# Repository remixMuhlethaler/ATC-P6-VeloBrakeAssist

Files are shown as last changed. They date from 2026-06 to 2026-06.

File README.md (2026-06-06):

# VeloBrake Assist — ATC-P6

**An open-source assistive cycling device for users with limb differences.**

> Developed at EPFL as part of the Assistive Technology Challenge (ATC) 2025–2026.  
> Team: Camilla Varotto · Hema Gouled · N'zian Koffi · Remy Mühlethaler  

---

## Overview

VeloBrake Assist is a custom-fit braking aid designed for a user with ectrodactyly of the left hand. The device enables safe, independent braking on a standard bicycle. It adapts the open-source [Project Caroline by Macu4]([https://www.macu4.com](https://www.hackahealth.ch/project-caroline-2021)) to the user's specific hand morphology and target bike.

The device consists of three integrated subsystems:

- **Hand-grip** — a custom TPU + PETG mold shaped from the user's hand, providing a secure and comfortable interface between the hand and the handlebar.
- **Braking system** — a stainless steel cable mechanism that transmits the user's wrist/arm downward movement into modulated brake actuation.
- **Attachment mechanism** — a commercial steel pipe clamp designed to fit standardized handlebar (without coatings).

The prototype is functional and has been validated by the user on their own bicycle. Further improvements are planned (see [Future Work](#future-work)).

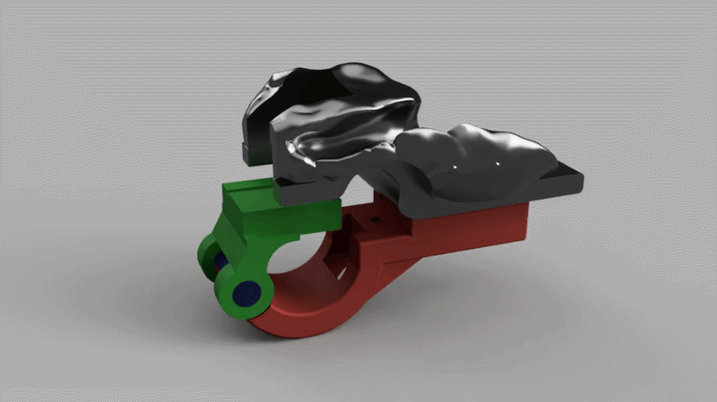
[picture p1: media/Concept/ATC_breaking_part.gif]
VeloBrake Assist Concept
 
## Media and Demonstrations

The operation of the prototype as well as the testing phases are documented in video format.

* [Access the complete Google Drive folder (Videos & Photos)](https://drive.google.com/drive/folders/1Wf3XGNz-UpR_hRMOGoVsbd66ucjs_gCT?usp=sharing)
---

## Repository structure

```
ATC-P6-VeloBrakeAssist/
├── docs/
│   ├── user_manual.pdf          # Assembly & use guide (≤3 pages)
│   ├── open_access_report.pdf   # Reproducibility report (≤10 pages)
│   └── final_presentation.pdf  # End-of-semester presentation (EPFL, 29.05.2026)
│
├── worksheets/
│   ├── traceability_matrix_v0.1.xlsx
│   ├── traceability_matrix_v0.2.xlsx
│   ├── traceability_matrix_v0.3.xlsx
│   └── traceability_matrix_v0.4.xlsx
│
├── cad/
│   ├── fusion/                  # Native Fusion 360 source files (.f3d)
│   ├── laser_cut/               # File for Laser cut the MDF piece on the top (.dxf)
│   └── exports/                 # Print-ready files (.stl)
├── media/
│   ├── photos/                  # Prototype photos (design iterations + final)
│   └── videos/                  # Verification & validation footage
│
└── README.md
```

---

## How to reproduce the prototype

Full step-by-step instructions are in [`docs/open_access_report.pdf`](docs/open_access_report.pdf).

Quick summary:

1. **Print the parts** — open the `.stl` files in `cad/exports/`. Recommended settings: PETG at 0.2 mm layer height. 
2. **Route the cable** — thread the stainless steel cable through the channel and crimp the end stops.
3. **Attach to the handlebar** — slide the bracket over the handlebar and tighten the fastening screw.

> **Note:** The hand-grip is user-specific. The current shape was molded from our user's hand using Fimo clay as an intermediate. To reproduce for a different user, reshape the mold in Fusion 360 using the `.f3d` source files in `cad/fusion/`.

---

## Design process

The project followed the **V-model** engineering process:

- **User requirements** (safety, comfort, portability & compatibility) were gathered through home visits and structured interviews.
- **System requirements** were derived: braking system, hand-grip, attachment mechanism.
- **Design & Prototype**, each subsystem went through design, prototyping, verification (bench tests), and validation (on-bike tests with the user).
- Three iterations of the traceability matrix and risk assessment tracked requirement coverage throughout the semester.

---

## Future work

The current prototype is functional but several improvements are identified for the next iteration:

- Formal mechanical testing (load, fatigue, release force)
- Integrated cable clamp for easier installation
- Metal shaft to improve attachment rigidity
- Compatibility testing on additional bike models

---

## Acknowledgements

Special thanks to our TAs Dounia and Aiden for their guidance throughout this project.  
This project builds on [Project Caroline by Macu4]([https://www.macu4.com](https://www.hackahealth.ch/project-caroline-2021)) — an open-source assistive cycling device.

---

*EPFL · Assistive Technology Challenge 2025–2026 · Group P6*

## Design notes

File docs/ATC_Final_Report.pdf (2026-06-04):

# VeloBrake Assist

# An Assistive Braking Device for Biking

Varotto Camilla, Hema Gouled, N’zian Koffi, Remy Mühlethaler

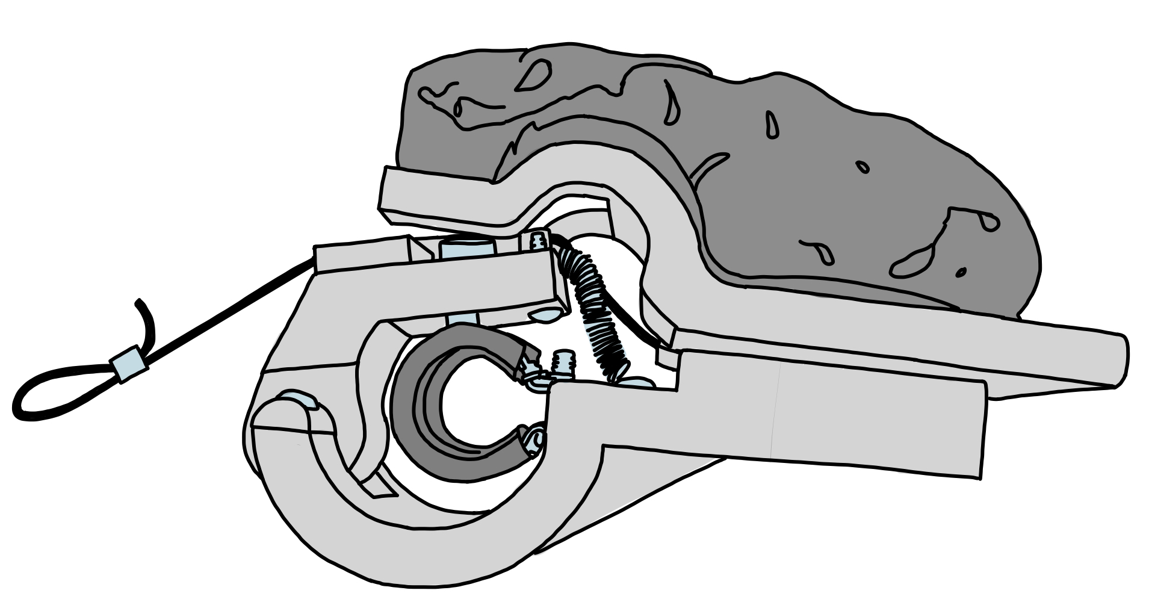
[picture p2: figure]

Open Access Report
Assistive Technology Challenge 2026 Group: P6, Adapted environment for ectrodactily Professors: Auke Ijspeert, Silvestro Micera, Josie Hughes TAs: Dounia Hassar, Aiden Xu

Lausanne, Spring 2026

## Contents

P6-ATC: Velobrake Assist

## 1. Introduction

VeloBrake Assist is an assistive device developed during a semester-long interdisciplinary project called Assistive Technology Challenge, organized by HackaHealth at EPFL (École Polytechnique Fédérale de Lausanne). Each team, composed of 4 Master’s students, was assigned a "challenger" with a specific need to solve an everyday challenge, adopting a "user-in-the-loop" approach.
The challenger assigned to this team is affected by ectrodactyly, also called split hand/foot malformation (SHFM), a rare congenital condition in which the development of the hand or foot is disturbed, causing the deficiency or absence of one or more central digits. The hands and feet of people with ectrodactyly are often described as "claw-like" due to their V-shaped appearance [3]. The challenger presented with one split hand, the left one, with the right one completely functional.
During the first meeting, the challenger described a daily life filled with constraints and limitations, and the continuous feeling of living in a world not shaped for them as they have issues with holding and grasping objects. One of the main things they wished to enjoy is biking. However, the conformation of their left hand does not allow them to grip the handlebar securely or to brake. Their goal was for the team to develop a device that could allow them to bike safely.
In this report, the development of VeloBrake Assist will be discussed, detailing the design choices and the iterative prototyping process behind them. Further steps needed to fully satisfy the needs of the challenger will also be presented.

## 2. Design Choices

### 2.1. User Requirements

### 2.1.1 Safety

As mentioned in the Introduction (Section 1), the user’s primary requirement is safety ("must-have"). To maneuver the bike safely, the user needs to grip the handlebars securely and to brake with both hands, not only the functional one. The braking mechanism should be modulable, allowing the user to slow down gradually rather than only stop abruptly, and should not activate accidentally. Additionally, immediate release of the handlebar must be possible in case of emergency, such as a fall. This was a critical limitation of a previous assistive tool they used (Figure 6.H) and the main reason they never felt fully safe while biking. Lastly, it should be sturdy enough to withstand the forces experienced while biking and braking.

2

### 2.1.2 Comfort

Comfort is also a key requirement ("must-have"); the device should therefore be mounted on the bike rather than worn. It should not feel bulky, but shaped to fit the user’s hand, and it should allow for natural and coordinated control of the bike.

### 2.1.3 Portability

Additionally, portability was identified as a desirable feature ("nice-to-have"). The device should be easily mountable, removable, and compatible with different bikes. The ideal scenario described by the user would be to carry the device in a backpack and mount it on any city bike when needed.

### 2.1.4 Support for Chronic Back Pain Management

Lastly, the user also reported suffering from chronic back pain, resulting from the overuse of the right hand to perform most daily actions. This leads to muscular imbalance between the two sides of the body, causing uneven load on the spine and additional issues while biking. While this condition is not directly addressed by the device, the user expressed the need for a solution that could help reduce this imbalance over time.

### 2.2. System Requirements

The user’s needs were translated into system requirements that guided the design of the device.

### 2.2.1 Braking System

The core of the device will be a braking system based on direct mechanical actuation of the brake through a cable. Braking shall be activated by a downward push of the wrist, a natural and comfortable movement for the user, and it shall be proportional to the force applied. The mechanism should be entirely passive, with no electronic components, ensuring simplicity and reliability. A spring return mechanism will be integrated to prevent accidental activation.

### 2.2.2 Hand-grip

To ensure both comfort and a secure grip, the device should incorporate a hand grip shaped to fit the user’s hand specifically, made from a soft material to maximize comfort during use.

3

### 2.2.3 Cable & Attachment Mechanism

Portability and compatibility will be addressed through two main design choices. First, a cable-based actuation system to ensure compatibility with various brake designs. Second, a secure attachment mechanism to fit the standardized handlebar diameter (removing the handlebar’s coatings), allowing the device to be mounted and removed from different bikes.

### 2.2.4 Weighted Sleeve

Finally, a weighted forearm sleeve should be used to address the muscular imbalance caused by chronic overuse of the right hand. A sleeve design should be chosen over conventional weighted tools, as the latter concentrate load on a single point of the arm, whereas the sleeve distributes it evenly across the forearm, which ensure comfortability for the user.

### 2.3. Final Design Specifications

Write about materials (PET-CF for robustness), specific design choices (eg the hole to fasten the attachment mechanism’s screw, type of screws), key design parameters.. The final design was build specifically for the challenger’s bike which was used for validation and verification, prioritizing robustness and safety on the user’s bike first and then compromising with some design specifications in order to create something that could be adaptable to different bikes.

### 2.3.1 Braking Mechanism: 3D designed parts, cable, spring

### 2.3.2 Hand-grip

I think we also need to ask sebastian which final parameters where used for the printing of TPU.

### 2.3.3 Clamping Collar & Fastening Screw

### 2.3.4 LaceUp Arm Sleeves

After discussing with the user, the "LaceUp Arm Sleeves" (Figure 6.J), a pair of weighted compression sleeves made with LYCRA® fiber weighing 1 lb each, were purchased from LaceUp (size Small/Medium) [1], an American brand specializing in weighted sport garments.

4

## 3. Reproducing Prototype

This is where the iterative, hands-on reality lives. Because design and prototyping were coupled for you, structure this as rounds of iteration rather than a linear list of steps:

3.1. 3D Printing Iterations

3D printing iterations (what changed between versions and why)

### 3.2. Molded Hand-grip

Obtaining an accurate mold of the user’s hand was the most user-specific step of the entire process. During one of the early sessions with the user, Pâte Fimo (a polymer clay) was used to capture the natural grip position of the left hand directly on the handlebar of the user’s own bike using a platform in PETG similar to the one used in the final design. This approach was key: it ensured that the resulting shape reflected not an idealized grasp, but the actual posture adopted during riding. The hardened Fimo mold was then 3D scanned to obtain a digital model, which was cleaned and prepared for printing. The first print was made in PETG to verify the fit and general shape. While dimensionally accurate, the rigidity of the material made the grip uncomfortable against the user’s skin. A second version was printed in TPU (thermoplastic polyurethane) to introduce softness. After user testing, the printing parameters were adjusted reducing infill and perimeter to obtain a softer and more compliant result that the user found comfortable and secure.

### 3.3. Attachment Mechanism

Attachment mechanism trials (what failed, what worked)

### 3.4. Bike Repair

The user’s bicycle required significant maintenance. The bicycle was collected from the user’s home and transported to PointVelo, the on-campus bicycle repair service, where the necessary repairs were carried out with the help of the staff.
The kickstand was first re-secured, as it had become loose due to some missing fastening screws. The tires were then inspected, as the user had reported rapid pressure loss. No punctures were found and the issue was attributed to the prolonged inactivity of the bike. The tires were then reinflated.

5

The brake cables were adjusted to reduce lever travel distance. This was achieved by partially unscrewing the cable anchor bolt on each brake caliper, pulling the cable through to take up the slack, and re-securing it. This adjustment was necessary to shorten the actuation range of the levers and free up sufficient clearance on the handlebar for the device to be mounted.
Finally, recurrent chain derailment during gear shifting was addressed by installing a rubber-tipped set screw on the seat tube, acting as a mechanical stop to prevent the chain from dropping off during gear changes.

### 3.5. User testing sessions for Validation and Verification

their feedback, and what it changed

## 4. Further Improvements

The current prototype successfully demonstrates the core concept of VeloBrake Assist, but several limitations were identified during the project that would need to be addressed before the device could be considered production-ready.

### 4.1. Metal Shaft

The most pressing mechanical concern is the long-term durability of the 3D-printed parts. Although PET-CF was chosen for its stiffness, the pivot axis of the lever is a point of concentrated stress and would benefit from being replaced by a metal shaft machined to tolerance. This upgrade would significantly increase the lifespan of the device and its resistance to repeated braking cycles.

### 4.2. Cable Clamp

The cable attachment is another area for improvement. Currently, the cable is terminated with a crimped end which, while functional, requires a specific tool to adjust or replace. A cable clamp system was designed as a next step to allow tool-free cable length adjustment, making the device more accessible for the user to install and transfer between different bikes. However, the 2mm-cable clamp that was purchased [2] proved too bulky, obstructing the sliding of the cable and limiting the braking action, and was therefore not implemented in the final prototype.

6

### 4.3. Stability Across Different Bikes

The current attachment mechanism was designed around the user’s own bike, with the handlebar grip removed to ensure a secure fit. While this approach achieves good stability on the current setup, transferring the device to a different bike may introduce variability due to differences in handlebar and brake geometry.
A promising avenue to address this would be a dual-point attachment system. A primary, rigid fixation point just inboard of the grip (where handlebar diameters are largely standardised across city bikes) would bear the majority of the braking forces. A secondary, lighter contact point at the grip itself would provide rotational stability without requiring a tight clamp, accommodating slight variations in grip diameter found across different bikes. This configuration could preserve the stability achieved on the current prototype while making the device genuinely transferable. However, the feasibility of this approach depends critically on the clamping force achievable at the primary fixation point: sufficient torque and a secure fastening system would be essential to ensure the device does not rotate or slip under braking load.

### 4.4. Mechanical and Environmental Testing

The prototype was validated through user testing sessions but has not undergone formal mechanical testing. Quantifying the forces involved during braking at the pivot axis, the cable attachment point, and the handlebar clamp would allow the design to be optimised and failure modes to be identified. This is particularly relevant if the device were to be reproduced or adapted for other users, as the current prototype should be regarded as a proof of concept.
Additionally, the device has not been tested under real-world weather conditions. Rain, temperature variation, and UV exposure are all likely to affect the mechanical properties of the printed parts and the cable over time. Weatherproofing the design through appropriate material selection and protective coatings would be necessary for reliable everyday outdoor use.

### 4.5. Two-hands device

Early in the design process, the possibility of developing a two-handed version of the device was considered, motivated by the user’s requirement for natural and coordinated bilateral movement. Such a configuration would place an assistive device on both handlebars, allowing the user to brake with a coordinated movement.
However, this concept was not pursued for two main reasons. First, the right handlebar controls gear shifting; attaching a fixed grip platform on this side would make it difficult

7

for the user from operating the gear lever. Second, having both hands resting on the device rather than one directly on the handlebar poses a significant safety risk in case of mechanical failure. Given that the prototype has not undergone formal mechanical testing, it was considered essential that the user retains at least one hand in direct contact with the handlebar at all times, as a safety measure. The priority was therefore to validate the braking function on the left side first, leaving the two-handed configuration as a potential avenue for future exploration once the device has been thoroughly tested.

## 5. Conclusions

8

## 6. Figures

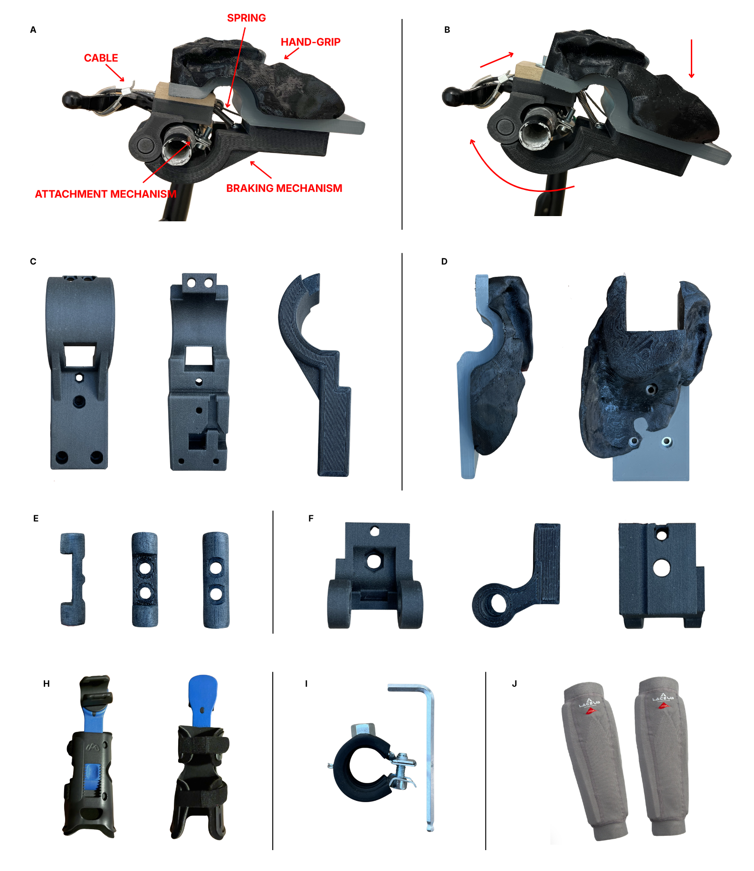
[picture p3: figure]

Figure 1: A. B. C. D. E. F. G. H. Frontal and dorsal view of the tool that the user previously used for biking; I. J. "LaceUp Arm Sleeves" purchased for the management of the challenger’s chronic back pain.

9

## References

[1] LaceUp. LaceUp Arm Sleeves. https://www.laceup.com/products/laceup-sleeves. Accessed: June 2026. 2026.
[2] SteelRopes24. Cable Gripper Clamp. https : / / www . steelropes24 . com / cable -gripper-clamp. (https://www.steelropes24.com/cable-gripper-clamp) Accessed: June 2026. 2026.
[3] Wikipedia. Ectrodactyly. https : / / en . wikipedia . org / wiki / Ectrodactyly. (https://en.wikipedia.org/wiki/Ectrodactyly) Accessed: June 2026. 2025.

10

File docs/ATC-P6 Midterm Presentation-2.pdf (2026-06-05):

# ATCP6

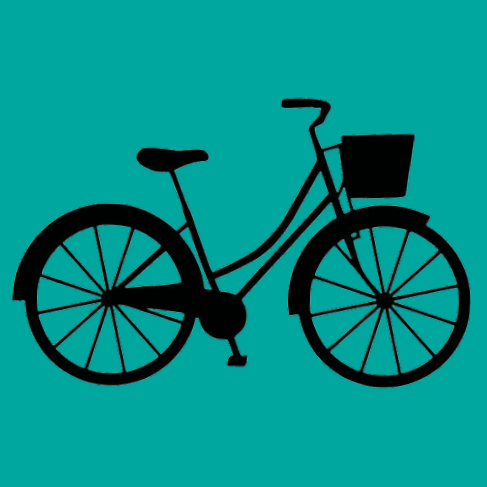
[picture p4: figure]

# Assistive Braking Device for Biking

Camilla Varotto, Hema Gouled, Nʼzian Koffi, Remy Mühlethaler

1

ATCP6 | 02.04.2026

2

# Presentation plan

- Definition of User Requirements
- Definition of System Specifications
- Existing solutions
- Brainstorming: presentation of possible ideas
- Presentation of our concept
- Budget Plan
- Future planning
- Expected Challenges

ATCP6

3

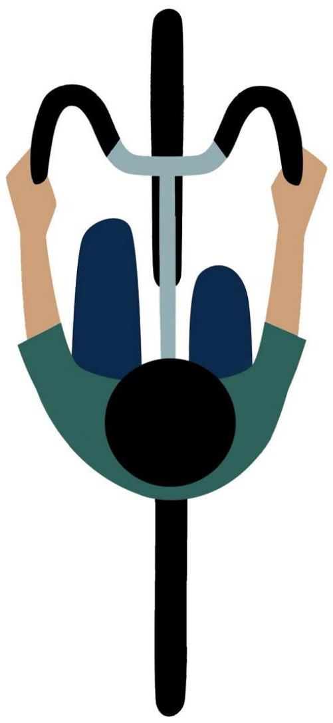
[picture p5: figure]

# What is the challenge?

- User with ectrodactyly: rare
genetic condition causing missing or malformed fingers
- A world not shaped for them: issues with grasping and holding objects
- Their wish: biking safely

4

# What are the needs of our challenger?

Safety
❏ | Secure grip for stable maneuvering
❏ | Ability to brake with the left hand
❏ | Modulable braking control
❏ | Immediate hand release in emergencies
❏ | Mechanism that avoids accidental braking activation
Comfort
❏ | Not worn by the challenger, but mounted on the bike
❏ | Natural, coordinated hand movement
❏ | Ergonomic device, shaped for the user
Portability & Compatibility
❏ | Easily mountable without assistance
❏ | Compatible with different bike types
❏ | Portable and easy to carry

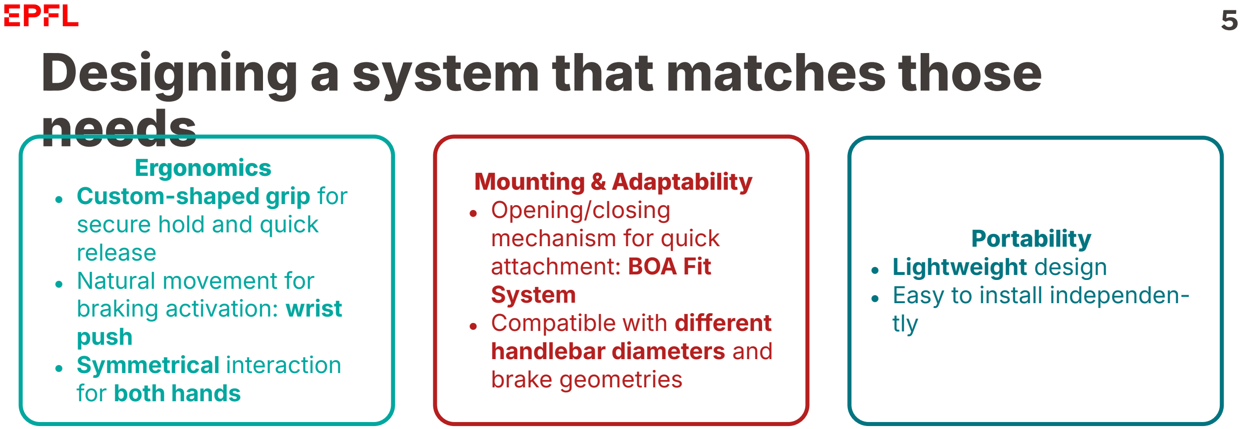
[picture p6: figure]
Designing a system that matches those needs; Ergonomics ● Custom-shaped grip for secure hold and quick release ● Natural movement for braking activation: wrist push ● Symmetrical interaction for both hands; Mounting & Adaptability ● Opening/closing mechanism for quick attachment: BOA Fit System ● Compatible with different handlebar diameters and brake geometries; Portability ● Lightweight design ● Easy to install independen- tly
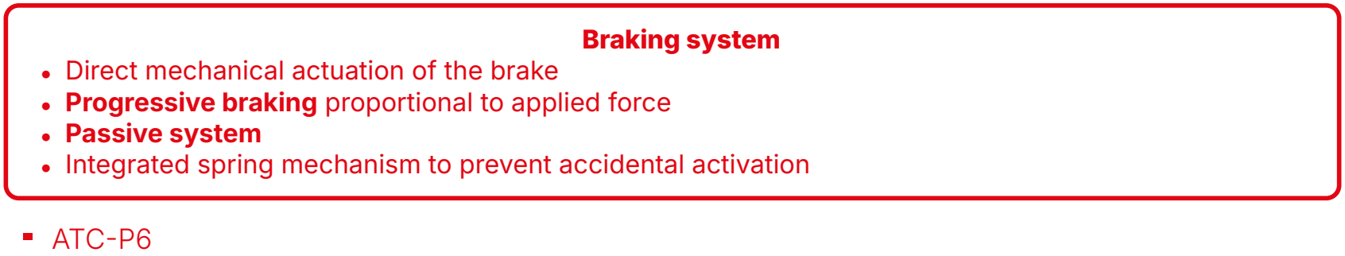
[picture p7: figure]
Braking system; ● Passive system

- Direct mechanical actuation of the brake
- Progressive braking proportional to applied force
- Integrated spring mechanism to prevent accidental activation

# Review of existing solutions

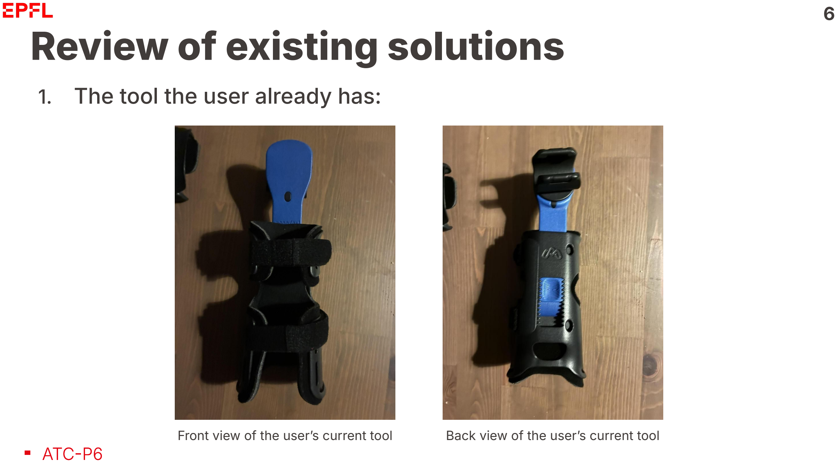
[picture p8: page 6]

6

1. The tool the user already has:
Front view of the userʼs current tool | Back view of the userʼs current tool

7

# Review of existing solutions

1. The tool the user already has:

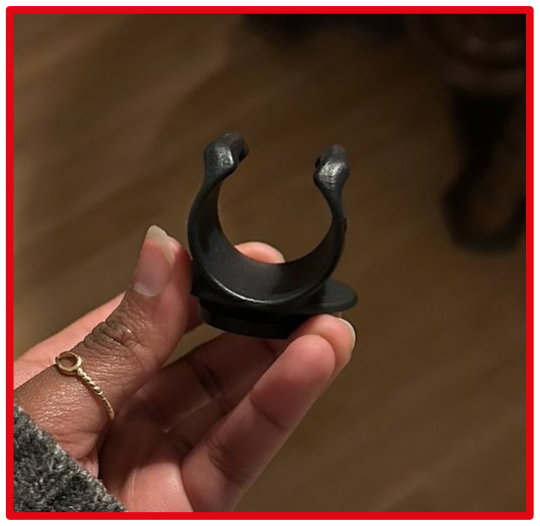
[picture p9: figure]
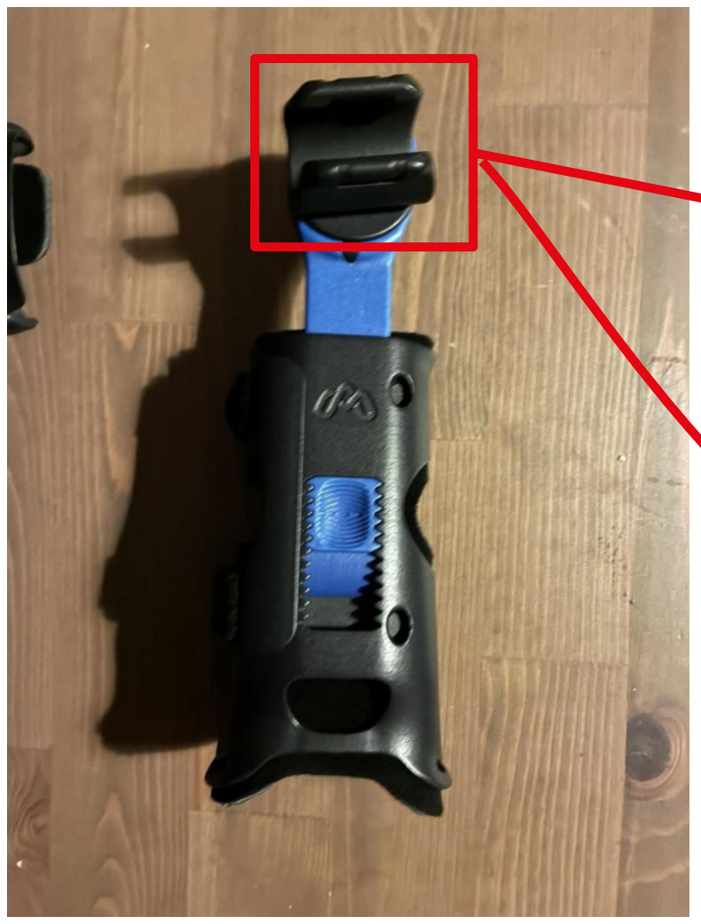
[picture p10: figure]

bike extension

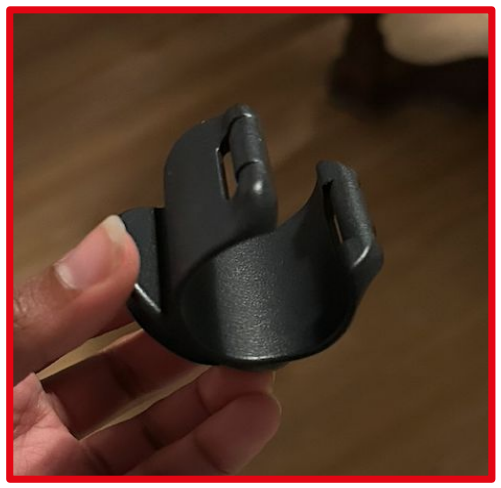
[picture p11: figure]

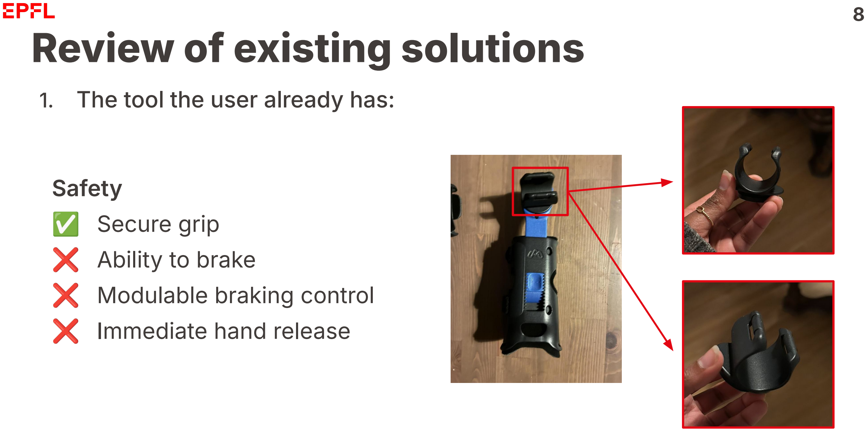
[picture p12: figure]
Safety Secure grip Ability to brake Modulable braking control Immediate hand release; 1. The tool the user already has:; Review of existing solutions

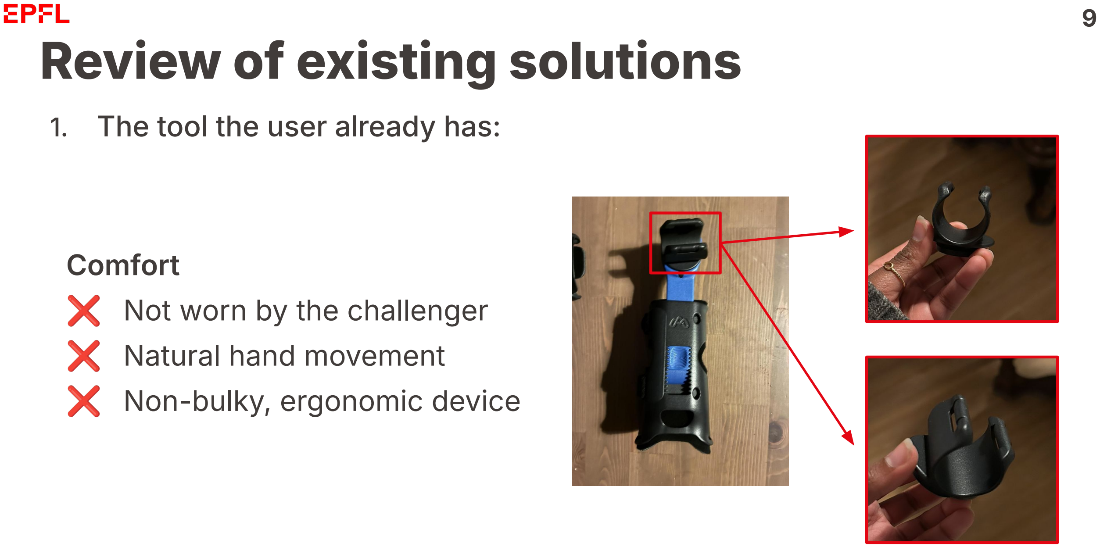
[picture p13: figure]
Comfort Not worn by the challenger Natural hand movement Non-bulky, ergonomic device; Review of existing solutions; 1. The tool the user already has:

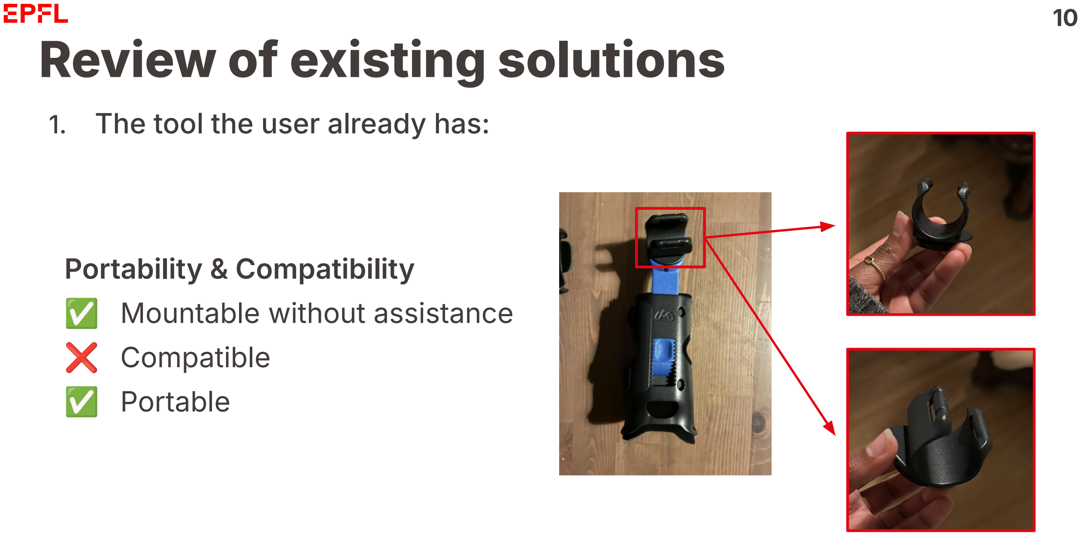
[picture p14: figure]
Portability & Compatibility Mountable without assistance Compatible Portable; Review of existing solutions; 1. The tool the user already has:

11

# Review of existing solutions

2. Coaster Brake (pedal braking):

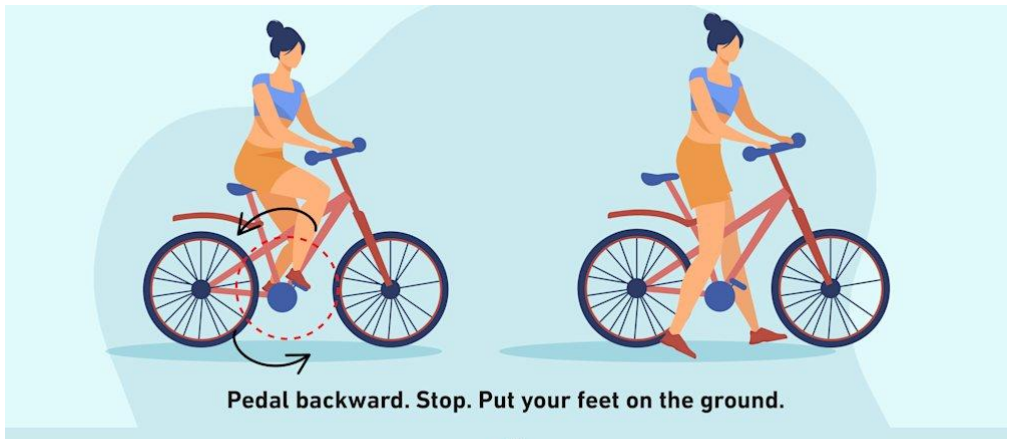
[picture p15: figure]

12

# Review of existing solutions

2. Coaster Brake (pedal braking):

Safety
Secure grip
Ability to brake
Modulable braking control
Immediate hand release

13

# Review of existing solutions

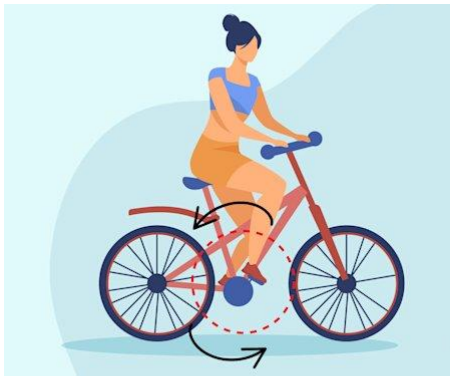
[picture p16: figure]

2. Coaster Brake (pedal braking):

Comfort
Not worn by the challenger Natural movement
Non-bulky, ergonomic device

14

# Review of existing solutions

2. Coaster Brake (pedal braking):

Portability & Compatibility Mountable without assistance Compatible
Portable

15

# Review of existing solutions

3. Project “Carolineˮ by Macu4

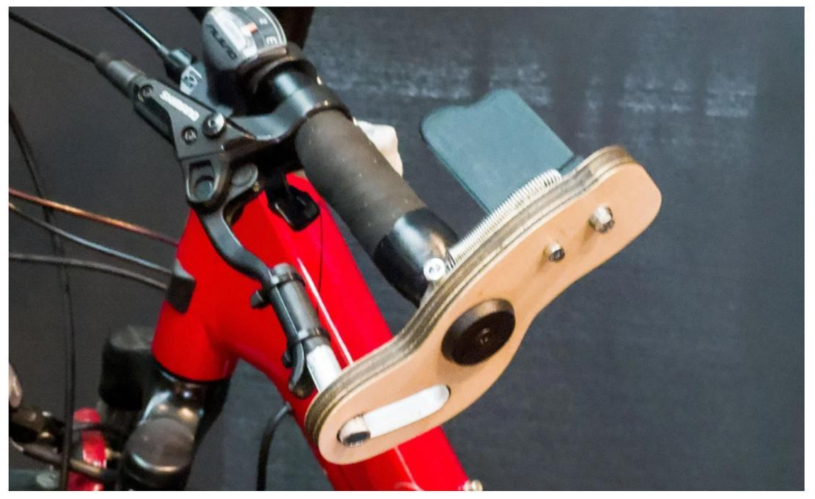
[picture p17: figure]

Project “Carolineˮ custom design installed on real bike

16

# Review of existing solutions

3. Project “Carolineˮ by Macu4

Safety
Secure grip
Ability to brake
Modulable braking control
Immediate hand release

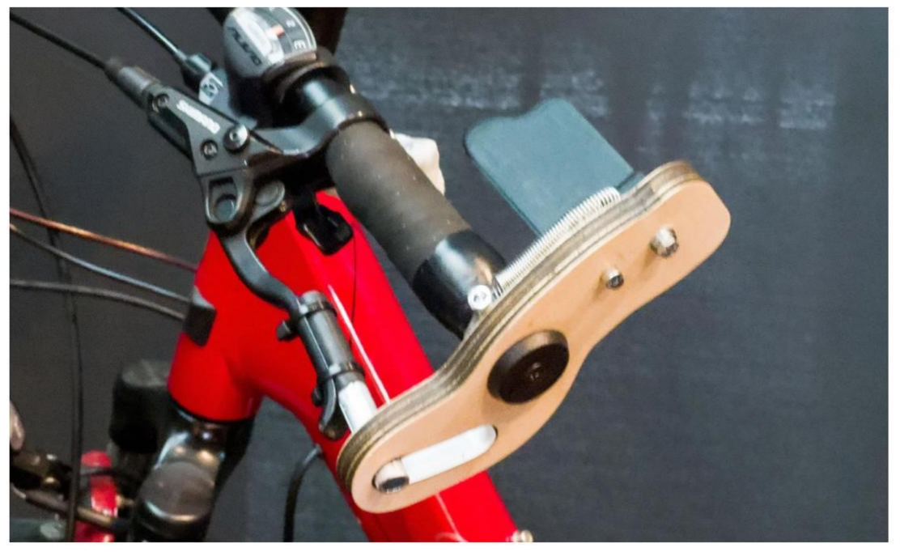
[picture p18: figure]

Project “Carolineˮ custom design installed on real bike

17

# Review of existing solutions

3. Project “Carolineˮ by Macu4

Comfort
Not worn by the challenger Natural hand movements

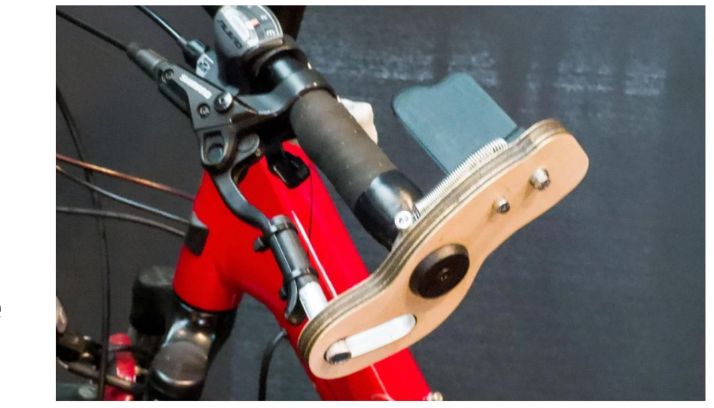
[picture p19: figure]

Non-bulky, ergonomic device

Project “Carolineˮ custom design installed on real bike

18

# Review of existing solutions

3. Project “Carolineˮ by Macu4

Portability & Compatibility Mountable without assistance Compatible
Portable

Project “Carolineˮ custom design installed on real bike

19

# Concept brainstorming:

1. Primal ideas

# Concept brainstorming:

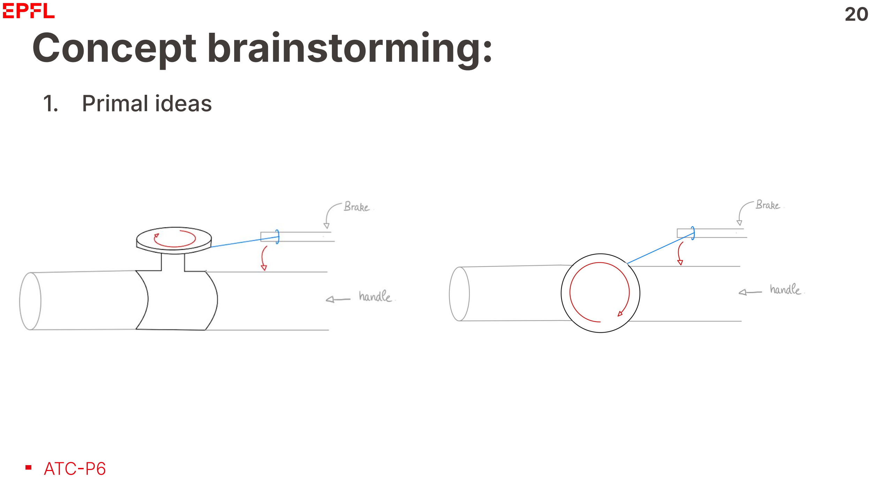
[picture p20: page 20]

20

1. Primal ideas

21

# Concept brainstorming:

2. After the feedback

⇒ Adapt the Macu4 mechanism

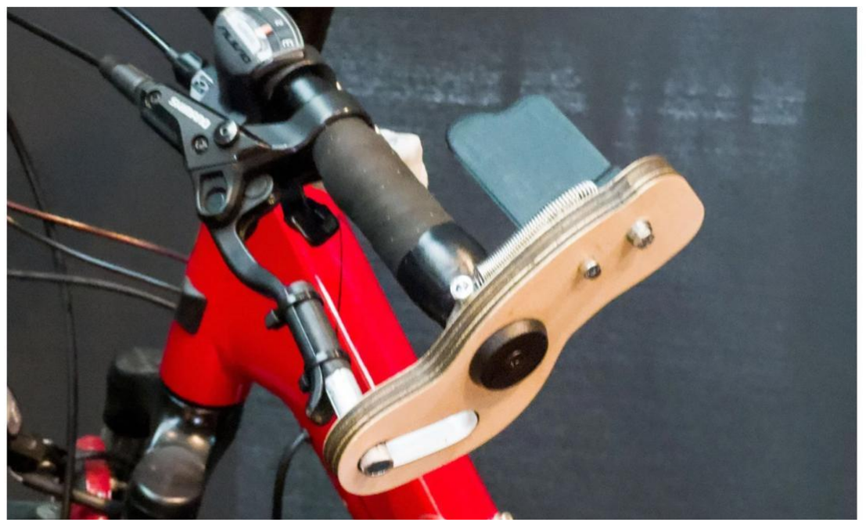
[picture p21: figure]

Idea approved by:
The challenger
The challengerʼs physical
therapist
The founder of Macu4

# Design of the prototype

22

Isometric view of the concept

# The concept

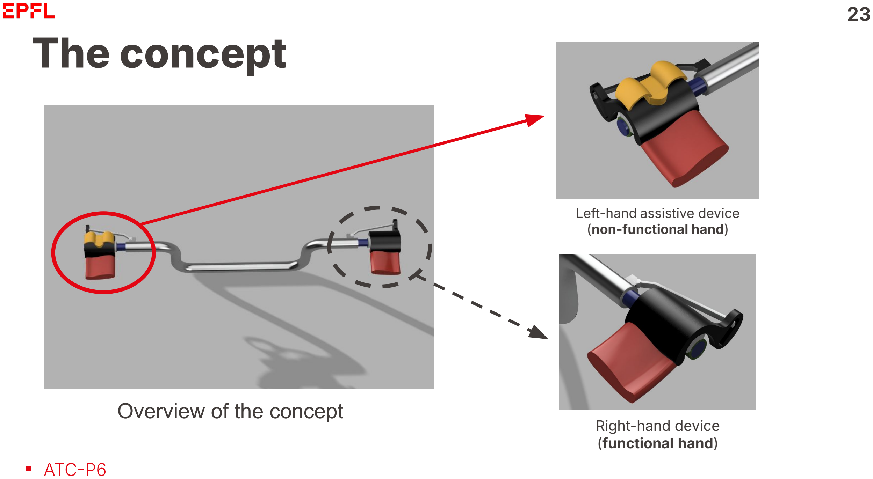
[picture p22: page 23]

23

Overview of the concept

Left-hand assistive device (non-functional hand)

Right-hand device
(functional hand)

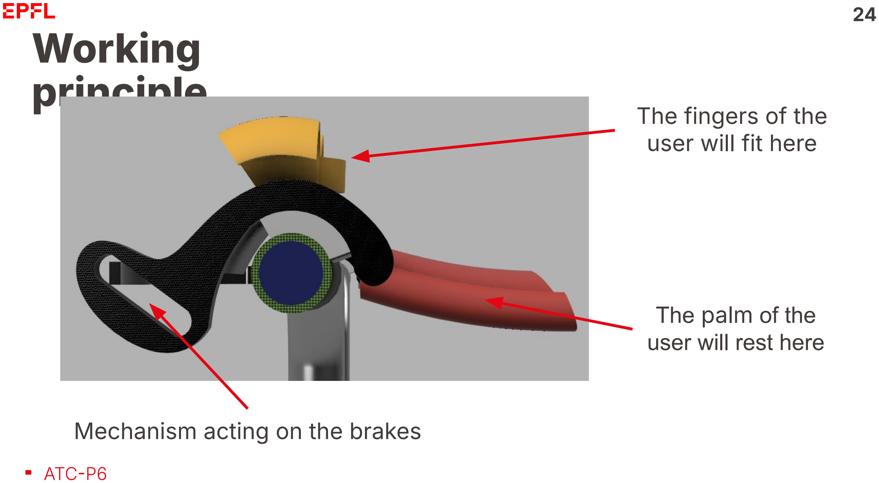
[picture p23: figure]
Working principle; The palm of the; user will rest here; The fingers of the user will fit here; Mechanism acting on the brakes

# Working principle

25

Resting position

Rotating

Braking

Brakes activation

# Adaptability on any bike

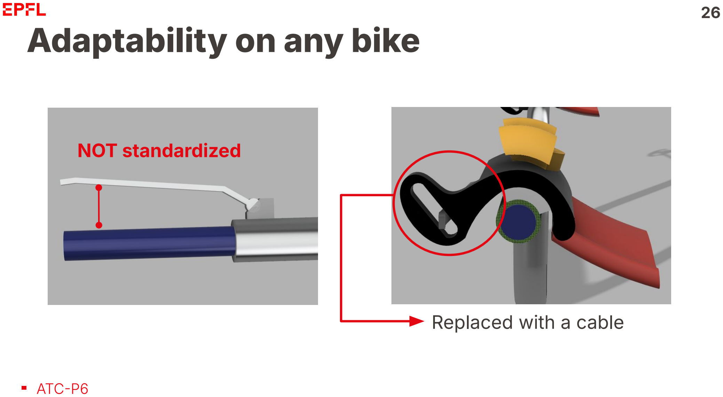
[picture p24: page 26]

26

NOT standardized

Replaced with a cable

# Adaptability on any bike

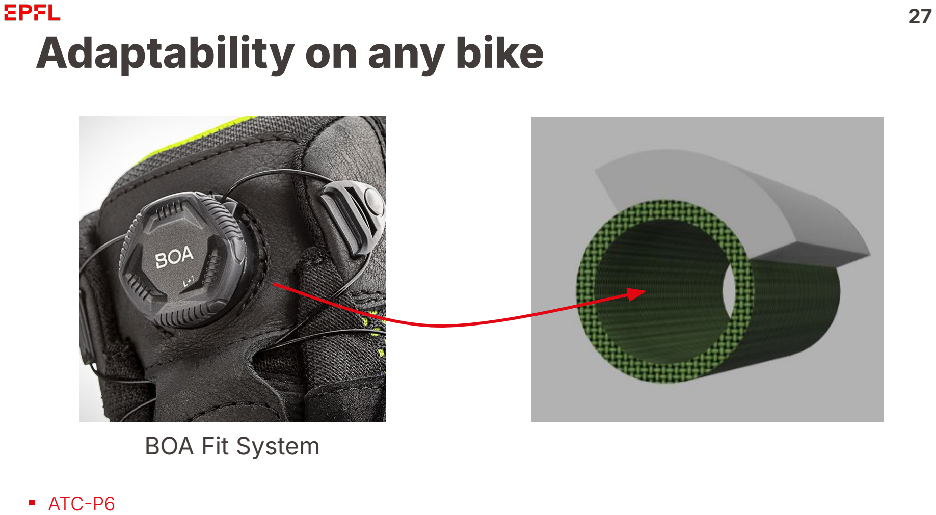
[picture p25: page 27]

27

BOA Fit System

# Pivot mechanism

28

Frame can rotate
relative to the grey
slider block
Dovetail sliding
mechanism (in the
grey block)

29

# Comfort 3D molding)


Adapted to the user,
3D molding

30

# Planning

ATC; team; Prototyping at DLL; Verification and validation; Final; presentation; Documentation; Iteration and switch material if needed

User | Testing on their bike and giving feedback 3D scan of their hand and

31

# Budget Plan

Category | Amount CHF | % Total | Notes
Travel & visits | 50.- | 5.8%
PLA 3D printing | 150.- | 17.6% | For testing & prototyping in 3D
Mechanical components | 50.- | 5.8% | Ball bearing, screws, springs, sliders…
BOA system | 60.- | 7% | Or similar
Stainless steel cable | 40.- | 4.7% | Sertissage & cable
Metal and composite machining | 500.- | 58.8% | PLA probably not strong enough
Total | 850.- | 100% | Initial allocated budget 1000.-

ID | Hazard | Risk | S | O | R | Mitigation Measure
R1 | Mechanical failure | Device does not brake/ slips | 3 | 2 | 6 | Material testing, safety factor in design, user testing protocol
R2 | Accidental activation | Brake triggered unintentionally while cycling | 4 | 2 | 8 | Lo-ratchet safety mechanism; resistance threshold tested with user
R3 | Poor fit/ comfort | Device is painful or unusable by challenger | 3 | 2 | 6 | Iterative prototype fitting sessions; adjustable straps & sizing
R4 | Bike incompatibility | Device cannot attach to all bike models | 2 | 3 | 6 | Universal mount design; tested on 2+ bike types before delivery

# Risk Assessment

33

# Any question?

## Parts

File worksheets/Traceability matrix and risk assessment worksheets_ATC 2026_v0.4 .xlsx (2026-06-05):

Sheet: Traceability matrix
User Requirement Specifications |  |  | Design Input Requirements |  | Verification |  |  |  | Validation
URS ID | URS | Importance [MUST / NICE TO HAVE] | DIR ID | DIR | Plan/method | Report result | Pass? [Y/N] | Comment | Plan / method | Report / result | Pass? [Y/N] | Comment
URS-01 | User wants to safely grip a bicycle handle to manouver it | MUST | DIR-01 | The device shall have a custom shape personalized for the user hand so that they can easily grip and hold on to the device which is mounted on the bike handle. | 3D design and modeling of the user hand with 3D scan | The user confirmed they could easily hold on to the custom-grip. | Y |  | Functional test with user: user confirmed ability to grip and manoeuvre the bike. | The user confirmed they could comfortably and securely grip the device while riding. | Y
URS-02 | User wants to be able to brake with her left hand when biking. | MUST | DIR-02 | The device will activate the brake mechanically whenever the user pushes down with her wrist on a platform. | Design of a device with the user input | Still needs to be tested with the user, but the mechanism pulls the brake when the lever is pushed down. | Y | Still needs validation. | Functional braking test with user. | The user confirmed the braking mechanism activates correctly when the wrist pushes down on the platform. | Y
URS-03 | User wants a device that can adapt to all bikes and that be easily switched on different bikes. | NICE TO HAVE | DIR-03 | The device shall have modulable parts with an opening mechanism so that it can be temporarily latched onto the bike handle and the brake. These parts will also need to be adaptable to different bike handles diameters and different brake-handle angles. | ~~~~BOA system, straps~~, modulable mechanism with a fastening screw~~ | The device can be mounted on different bikes with standard-sized handle bars by tightening and untightening a screw directly in the bike handle of the bike. To mount the device the handle coatings will need to be removed. The use of a cable to pull the brake allows the device to be mounted on bikes with different brake-handle angles. | Y |  | Mounting test on two different standard-sized bikes. | The device can be mounted on and removed from standard-sized handlebars, and the cable system adapts to different brake-handle angles. However, switching between bikes requires prior removal of the handlebar grip coating, which is a one-time manual step and not a quick swap. The "easily switched" aspect of the requirement is therefore not fully met. | N | The original requirement of easy switching between bikes has been partially abandoned for safety reason. The device is demountable and compatible with standard handlebars, but mounting requires the handlebar grip coating to be removed beforehand, which is feasible.
URS-04 | User wants to be able to remove their hand from the bike handle in case of urgency | MUST | DIR-04 | The custom shaped part of device that allows gripping shall also enable easy and quick removal of the user's hand. | 3D design and modeling of the user hand with 3D scan | The hand-grip doesn't trap the user's hand, confirmed with the user. | Y |  | Emergency release test with user. | The user confirmed they could remove their hand quickly and without difficulty in a simulated emergency scenario. | Y
URS-05 | User wants a device that does not feel bulky or unnatural. | NICE TO HAVE | DIR-05 | The device shall be mounted on the bike, not worn by the user. The movement performed to activate the braking system shall be natural, such as pushing down on a platform/lever with her wrist. | Design and discuss with the user's input. | Still needs to be confirmed with the user. However, the device was designed to be mounted on the bike and the natural activating movement was discussed and confimed with the user . | Y | Still needs validation. | User feedback session on comfort and naturalness of activation movement. | The user confirmed the activation movement felt natural and that the device did not feel bulky or intrusive. | Y
URS-06 | User wants a device that is mountable independtly by them without requiring the assistance from another person. | NICE TO HAVE | DIR-06 | The opening-closing mechanism used to make the device mountable on different bikes shall be easy to operate. The mounting/dismounting mechanism shall be kept as simple as possible. | Design and discuss with the user's input. | Still needs to be confirmed with the user. However, the device requires the handlebar coatings to be taken off, which is not something easy and quick to do. In principle, we achieved a design that is quite easy to mount with one hand with reduced functionality, but the user will need help to remove the coatings. | N |  | Independent mounting trial with user. | The user was able to mount the device on the handlebar independently with one hand; however, removal of the handlebar coatings required assistance. This requirement is partially met. | N | Mounting the device independently requires removal of the handlebar coatings, which the user cannot perform alone. Accepted as a known limitation given the chosen fixation approach.
URS-07 | Users wants a device that she can carry around and mount in case she needs to rent a city bike | NICE TO HAVE | DIR-07 | The device shall not be to bulky and heavy, but made of light materials. | Weight the device | The device is light, but for what we mentioned above, it won't be usable on city bikes as the user won't be able or allowed to remove the handlebar coatings off them. |  | It is light, but not mountable on city bikes. | City-bike compatibility test. | The device cannot be mounted on city bikes because the handlebar coatings cannot be removed by the user or may not be removed at all on rental bikes. | N | Accepted limitation: the fixation approach requires handlebar coating removal, which is not feasible on rental/city bikes. The device remains functional on personal bikes.
URS-08 | User wants to perform the same movement with both hands. So that coordination is facilitated. | MUST | DIR-08 | Two devices shall be made, one for the functional and one for the non functional hand. The same mechanism (pushing down with her wrist) will be applied ot both, but with slighlty different implementation to adapt them to the different shapes of her hands. | Design and discuss with the user's input. | Two similar devices with the same mechanism and different hand-grips were designed. | Y |  | The two-device approach was abandoned for safety reasons (risk of obstructing access to the gear shifters) and to preserve the user's access to the handlebar controls on the right side. | The user confirmed she felt comfortable and safe using only the left-hand device. The right side was kept free to allow unrestricted access to the gear shifters and other handlebar controls. | N | The bilateral symmetry goal was deprioritised in favour of safety and usability.
URS-09 | User wants a mechanism that is safe and it does not activate by mistake. | MUST | DIR-09 | The device shall have a spring counteracting the sliding mechanism used to activate the brake, so that the force to activate it will not be minimal. | Design | Still needs to be tested with the user, but the mechanism works. | Y | Still needs validation. | Safety activation threshold test with user. | The user confirmed the spring resistance prevents accidental activation; the mechanism requires a deliberate downward push to engage. | Y
URS-10 | Users wants a device that brakes modulably, not only brakes completely or not. | MUST | DIR-10 | The device will be mechanic and passive activated directly by the user movement. The degree of braking will be determined by how hard the user pushes down with their wrist. | Design | Still needs to be tested with the user, but the mechanism works. | Y | Still needs validation. | Modular braking test across a range of applied forces. | The user confirmed that varying wrist pressure produces proportional braking, with no binary on/off behaviour observed. | Y
URS-11 | User wants a weighted sleeve to strength train her left side and balance the weight. | NICE TO HAVE | DIR-11 |  | Design | Sleeve was ordered online. | Y | Still not delivered. | User trial with weighted sleeve. | The user confirmed the sleeve provides perceptible resistance on the left side and complements the device for strength training purposes. | Y

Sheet: Risk assessment
Risk identification, evaluation and control |  |  |  |  |  |  | Risk verification
Risk ID | Hazard | Risk | Severity ("S") | Occurrence ("O") | Risk ("R") | Risk control measure | Risk mitigated? [Y/N] | Comment
R1 | Mechanical failure | Device does not brake/slips | 3 | 2 | 6 | Material testing, safety factor in design, user testing protocol | Y | No slippage risk identified. However, no fatigue testing has been conducted on the mechanism. Force distribution across contact zones has been optimized and the device has been designed to maximize structural robustness, but residual risk of breakage under repeated loading cannot be fully excluded.
R2 | Accidental activation | Brake triggered unintentionally while cycling | 4 | 2 | 8 | Lo-ratchet safety mechanism; resistance threshold tested with user | Y | Spring has been added to the mechanism to actively prevent unintentional engagement. Resistance threshold validated through testing.
R3 | Poor fit/comfort | Device is painful or unusable by challenger | 3 | 2 | 6 | Iterative prototype fitting sessions; custom hand mold produced for the challenger to ensure anatomical fit. | Y | A custom hand mold was produced for the challenger to ensure an anatomical fit. The resulting device fit was reviewed and approved by the challenger.
R4 | Bike incompatibility | Device cannot attach to all bike models | 2 | 3 | 6 | A secure screw-based fixation was chosen over a universal mount to guarantee reliable attachment and eliminate the risk of slippage or improper mounting on standard bikes. Compatibility is limited to bikes whose handlebar coatings can be removed. | N | The device is not compatible with bikes fitted with grip covers on the handlebars. A good fixation mount was deliberately chosen over a universal solution to prioritize secure and reliable attachment, eliminating the risk of improper fixation.

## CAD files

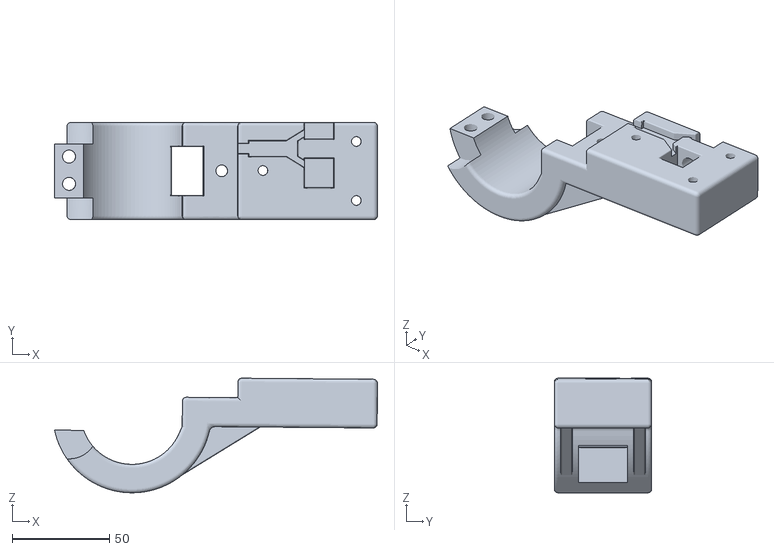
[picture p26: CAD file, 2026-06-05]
cad/exports/ATC_breaking_rotating_part.stl
165.7 x 50.0 x 58.8

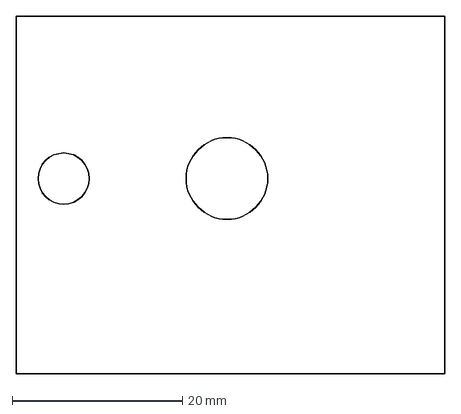
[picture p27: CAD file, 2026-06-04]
cad/laser_cut/Decoupe_LASER_MDF.dxf
50.3 x 42.0 mm

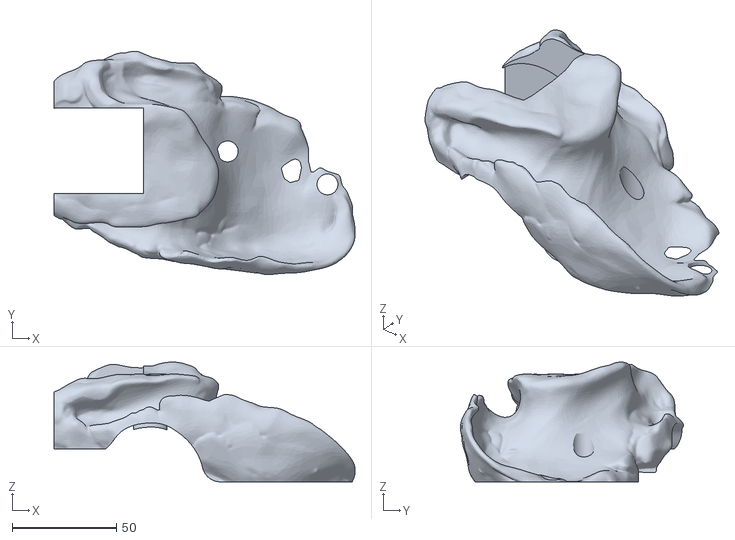
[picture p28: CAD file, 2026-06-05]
cad/exports/ATC_breaking_support_TPU.stl
144.2 x 106.9 x 57.4

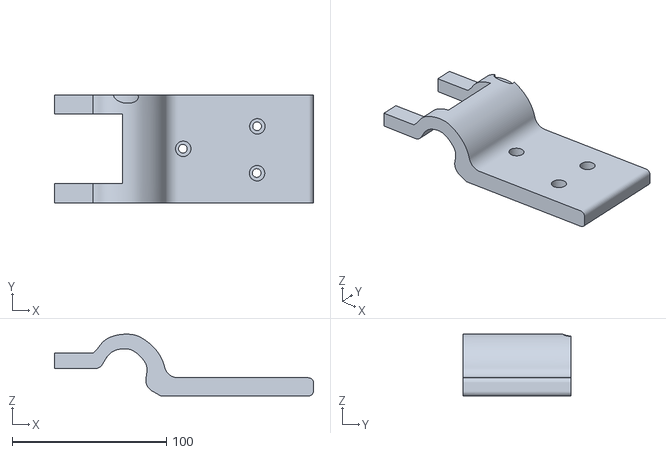
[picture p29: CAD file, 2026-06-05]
cad/exports/ATC_breaking_support_PETG.stl
167.7 x 70.0 x 40.0

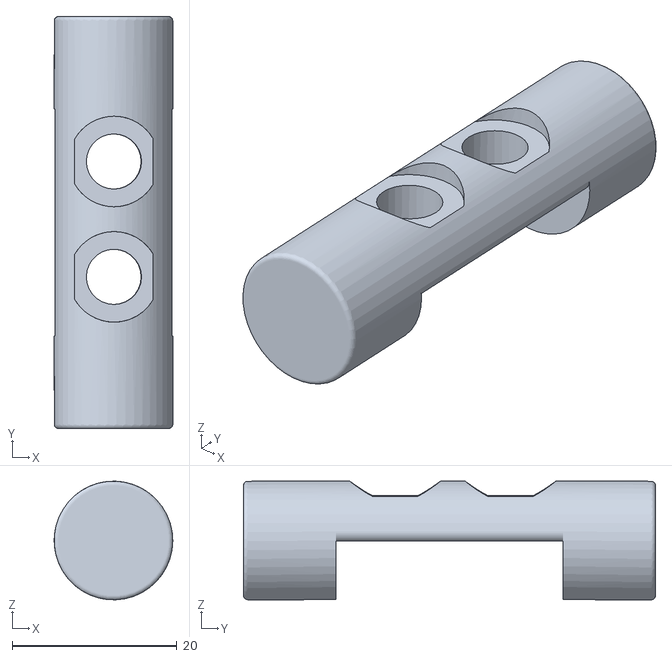
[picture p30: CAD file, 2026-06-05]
cad/exports/ATC_breaking_axis.stl
14.4 x 50.0 x 14.4

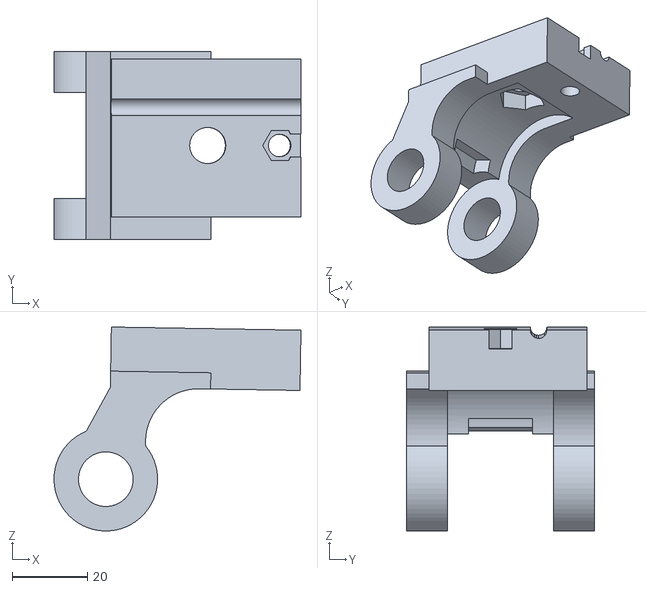
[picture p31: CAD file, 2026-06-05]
cad/exports/ATC_breaking_fixiture.stl
65.5 x 50.0 x 54.1

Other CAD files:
cad/fusion/ATC_breaking_full.f3d

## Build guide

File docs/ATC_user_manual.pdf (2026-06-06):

# VeloBrake Assist

# User Manual

Varotto Camilla, Hema Gouled, N’zian Koffi, Remy Mühlethaler


Assistive Technology Challenge 2026 Group: P6, Adapted environment for ectrodactily Professors: Auke Ijspeert, Silvestro Micera, Josie Hughes TAs: Dounia Hassar, Aiden Xu

Lausanne, Spring 2026

## Contents

P6-ATC: Velobrake Assist — User Manual

## 1. Introduction

VeloBrake Assist was designed to help cyclists with reduced hand function ride more safely and confidently. By providing a secure and comfortable hand grip on the handlebar together with an intuitive braking mechanism, the device enables users to maintain control of their bike without having to completely relearn how to ride.
Compatible with most bicycles featuring standard-sized handlebars, VeloBrake Assist attaches securely to the handlebar once the original grip coating is removed. The system can also be mounted and removed, allowing it to be transferred between different bicycles rather than remaining permanently fixed to a single bike.
Braking is achieved through a simple downward wrist movement applied to a custommolded hand support. As pressure is applied, a cable mechanically activates the bike brake, providing smooth and modulable braking control. While some practice may be required at first, the device is designed to feel as natural and intuitive as possible, allowing the user to focus on the ride rather than the mechanism itself.

## 2. The Device

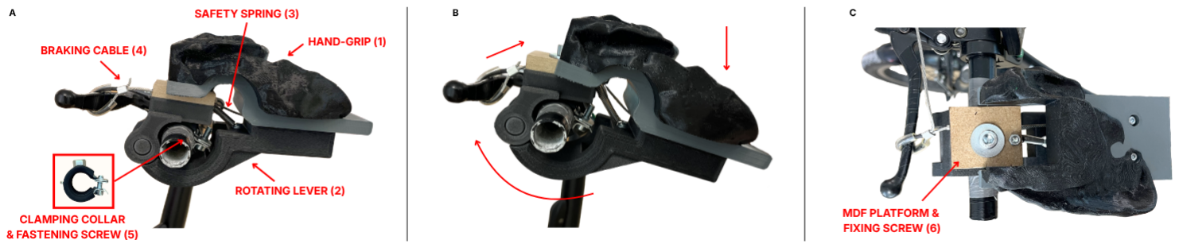
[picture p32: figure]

Figure 1: VeloBrake Assist. A. Components; B. Activation movement; C. MDF platform & fixing screw.

Hand Grip (1)
The hand grip is the part on which the user rests their hand during rides. It was designed from a 3D scan of a custom mold to ensure the best possible fit and comfort. The custom hand grip is partially manufactured in TPU (in black) to improve comfort and flexibility, while the remaining structure is made of PETG.

Rotating Lever (2)
The rotating lever is the moving part of the mechanism. It is made of PET-CF and anchors the braking cable and the safety spring. When the user pushes downward with their wrist, the rotating lever rotates and pulls the braking cable, activating the bicycle

2

brake.

Safety Spring (3)
The safety spring provides resistance to the mechanism in order to reduce the risk of accidental braking. Its role is to keep the rotating lever in its resting position until sufficient pressure is intentionally applied.

Braking Cable (4)
The braking cable is a 2 mm steel cable that connects the rotating lever to the bicycle brake. The cable is attached to the rotating lever and the brake using cable grippers. When the mechanism is activated, the cable is pulled through the guide canal and activates the brake.

Attachment Mechanism: Clamping Collar, Fastening & Fixing Screw (5)
The attachment mechanism is a steel clamping collar internally coated with rubber to improve grip and stability on the handlebar. Its ends are tightened together via a fastening screw, securing it onto the handlebar. The fixed part of the braking mechanism connects to the clamping collar via a fixing screw, forming a rigid and stable assembly once tightened.

## 3. How to Mount & Use the Device

### 3.1. Mounting the Device on the Bike

1. Remove the original grips or coatings from both sides of the bicycle handlebar.

### 2. Position the clamping collar on the handlebar and tighten the fastening screw using

a flathead screwdriver until firmly secured.

### 3. Screw the rest of the device onto the clamping collar using an Allen key to tighten

the fixing screw.

### 4. Pass the braking cable around the existing brake lever on the handlebar and secure

it fastening a 2mm steel cable gripper with pliers. If the cable tension needs to be adjusted, remove the cable gripper with pliers, reposition the cable to the desired length, and secure it with a new 2mm steel cable gripper.

3

### 3.2. Using the Device

1. Place the left hand comfortably on the hand grip and the right hand on the handlebar. Maintain a secure hold with both hands while riding.

### 2. To brake, push downward with the left wrist to activate the mechanism, and pull the

brake lever with the right hand.

## 4. Precautions and Safety

To ensure safe and reliable use of VeloBrake Assist, please carefully follow the recommendations below before and during use.

- The device is recommended for use on the left hand only. The right hand should grip the handlebar directly to maintain control in case of mechanism failure and to ensure greater stability.
- The device is manufactured using 3D-printed PET-CF components. While the material offers good mechanical resistance, it may be damaged by strong impacts or prolonged exposure to high temperatures. Avoid leaving the device in excessively hot environments or under direct sunlight for extended periods.
- Before each use, verify that the device is securely attached to the handlebar. Apply moderate force to check for any movement or instability. If the device shifts or rotates, tighten the fastening screw before riding.
- Regularly inspect the brake cable to ensure it is correctly tensioned and securely connected. A cable that is too loose may disengage from the brake mechanism during use, creating a safety hazard.
- VeloBrake Assist is intended for use in relatively controlled riding environments such as city streets, bike paths, and everyday commuting. The device is not designed for aggressive riding conditions such as mountain biking, jumps, or steep downhill trails.
- Before each ride, inspect the device for any visible signs of wear, cracks, deformation, or malfunction. If any component appears damaged or does not operate correctly, do not use the device until it has been repaired or replaced.
- Users are encouraged to practice using the braking mechanism in a safe and controlled area before riding in traffic or crowded environments.
- If the device needs to be mounted on a different bicycle, please contact the team to ensure that the installation is performed correctly.

4

## 5. Contacts

For any questions regarding this user manual or the VeloBrake Assist device, please contact the development team at:

camilla.varotto@epfl.ch

hema.gouled@epfl.ch

remy.muhlethaler@epfl.ch

nzian.koffi@epfl.ch

5

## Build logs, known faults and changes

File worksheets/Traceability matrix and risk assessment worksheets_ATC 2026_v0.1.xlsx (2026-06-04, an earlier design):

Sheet: Traceability matrix
Note: Orange text is to be replaced or deleted!
User Requirement Specifications (Columns due 13/03/26) |  |  | Design Input Requirements (Columns due 03/04/26) |  | Verification (Columns due 15/05/26) |  |  |  | Validation (Columns due 22/05/26)
URS ID | URS | Importance [MUST / NICE TO HAVE] | DIR ID | DIR | Plan/method | Report result | Pass? [Y/N] | Comment | Plan / method | Report / result | Pass? [Y/N] | Comment
URS-01 | User wants to safely grip a bicycle handle to manouver it | MUST | DIR-01
URS-02 | User wants to be able to brake with her left hand when biking | MUST | DIR-02
URS-03 | User wants a device that can adapt to all bikes and that be easily switched on different bikes | MUST | DIR-03
URS-04 | User wants to be able to remove their hand from the bike handle in case of urgency | MUST | DIR-04
URS-06 | User wants a device that does not feel bulky or unnatural. | NICE TO HAVE | DIR-05
URS-07 | User wants a device that is mountable independtly by the user without requiring the assistance from another person | NICE TO HAVE | DIR-06
URS-06 | User wants a weighted sleeve to strength train her left side and balance the weight. | NICE TO HAVE | DIR-07

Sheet: Risk assessment
Note: Orange text is to be replaced or deleted!
Risk identification, evaluation and control (Columns due 03/04/26) |  |  |  |  |  |  | Risk verification (Columns due 22/05/26)
Risk ID | Hazard | Risk | Severity ("S") | Occurrence ("O") | Risk ("R") | Risk control measure | Risk mitigated? [Y/N] | Comment
etc…
Note: Everytime you make significant changes to this document (e.g. for deliverables) you should increase the versioning of the file from v1.0 to v2.0 etc. For drafts for a deliverable you could use v0.1 to v0.2.
